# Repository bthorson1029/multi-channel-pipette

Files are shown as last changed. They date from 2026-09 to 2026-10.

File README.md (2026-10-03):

# multi-channel-pipette: motorized-lift redesign

A 96-channel pipette for 8 x 12 well plates, built from low-cost parts: 2020 aluminum extrusion,
laser-cut 3 mm steel, 3D-printed parts, NEMA17 steppers and an Arduino. This fork redesigns
[Its-Triggy/multi-channel-pipette](https://github.com/Its-Triggy/multi-channel-pipette) (build
video: [youtu.be/2TTu-Lkz2Eo](https://youtu.be/2TTu-Lkz2Eo)) to run itself instead of being worked
by hand with a lever. This repo holds only the redesign; the original design's files are in its
history (commit `4b765e6` and earlier).

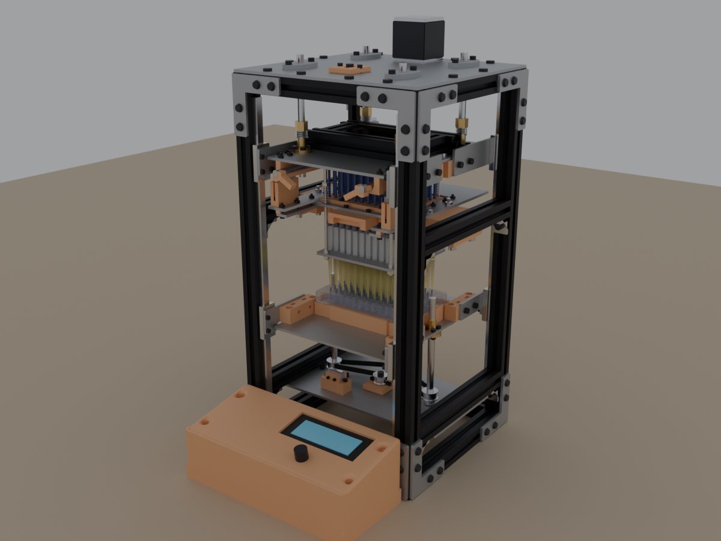
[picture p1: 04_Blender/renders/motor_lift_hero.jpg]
The motorized-lift build mid-dispense


## Status

**Designed and simulated, not yet built.** The whole machine is modeled in Blender down to every
screw. It passes collision and clearance checks through a complete run, and the firmware compiles
for the Uno and passes a host-side test suite. Nothing has been built or run on hardware yet.
Before trusting it with samples, you'll need to measure or set:

- Volume calibration tables for each syringe cartridge (`CAL_*` in `Config.h`)
- Labware heights for your tip rack and reservoir (placeholders in `Config.h`)
- The plunger level-check tolerance (`PLUNGER_TILT_MAX_MM`)
- The KFL08 bolt spacing (the plates assume 37 mm) and your syringes' flange dimensions
- The force needed to strip the tips, and the D-shaft clamp's preload
- The tip cone size for your tips: order the sizing set first (see "Tip cones" in
  [`01_Hardware/README.md`](01_Hardware/README.md))

The frame layout was reconstructed from the original's build video, since the original has no
assembly file. Part shapes are exact; some positions and lengths are estimates.

## What changed from the original

| | Original | This redesign |
|---|---|---|
| Moving the tips into the labware | Lever lowers the whole head | Head fixed; a motor raises the bed on two T8x2 lead screws |
| Plunger drive | 4 motors, one per screw | 1 motor on the top plate drives all 4 T8x2 screws through a GT2 belt |
| Plunger nuts | Plain | Anti-backlash, 2 mm lead (48 steps/uL) |
| Plunger homing | Limit switches | 3 slotted optical sensors, with a check that the plate is level |
| Tip removal | No ejector | Tip ejector: the plunger runs 11.5 mm past home and strips the tips a row at a time |
| Syringes | Fixed in the head | A cartridge that slides out the front like a drawer, held by two quarter-turn levers |
| Control box | Hung on the frame | Lies in front of the base with its screen tilted 10 deg toward you |
| Frame height | 400 mm | 430 mm, so an empty tip rack slides out under freshly loaded tips |

## How a run works

1. **Load tips.** Put a full tip rack in the nest and raise the bed; the nozzles press into the
   tips. Lower the bed and the tips stay on. The empty rack slides out under them.
2. **Aspirate.** Swap in the source (a reservoir or plate), raise the bed so the tips are in the
   liquid, and draw.
3. **Dispense.** Swap in the destination plate, raise the bed, and dispense. Forward mode blows
   out after a single transfer; reverse mode is for repeat dispenses.
4. **Eject.** Put a waste tray on the bed and choose *Eject tips*: the plunger runs past home and
   the ejector plate strips the tips, front rows first.
5. **Swap cartridges.** Loosen the four clamp thumbscrews, turn the two levers a quarter turn and
   slide the cartridge out the front.
   Pick the new one's profile in the *Cartridge* menu.

The Blender model plays this whole run on its timeline (680 frames).

| Tips in the reservoir | Cartridge out |
|---|---|
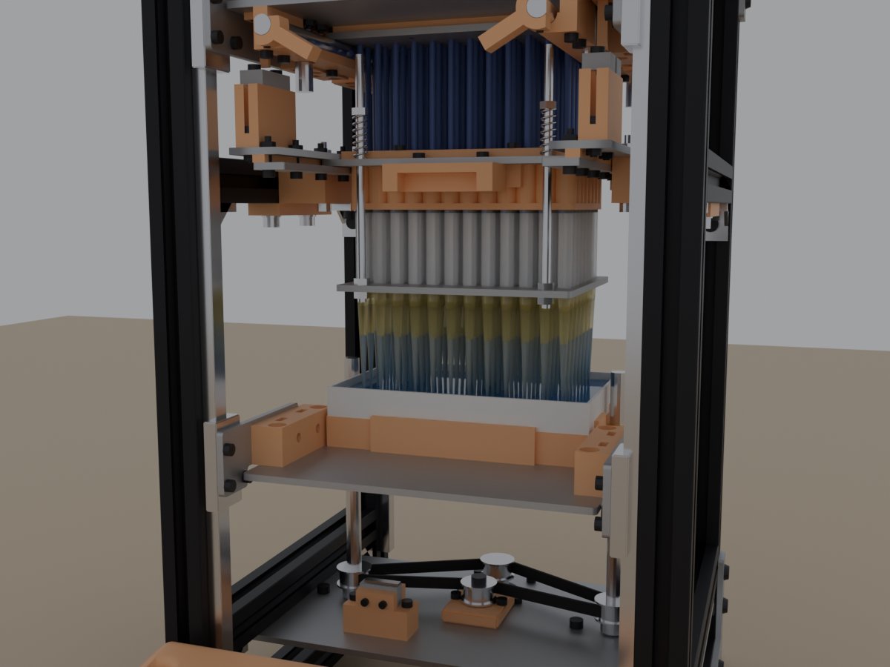
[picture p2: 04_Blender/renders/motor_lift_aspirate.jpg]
Aspirating from a reservoir
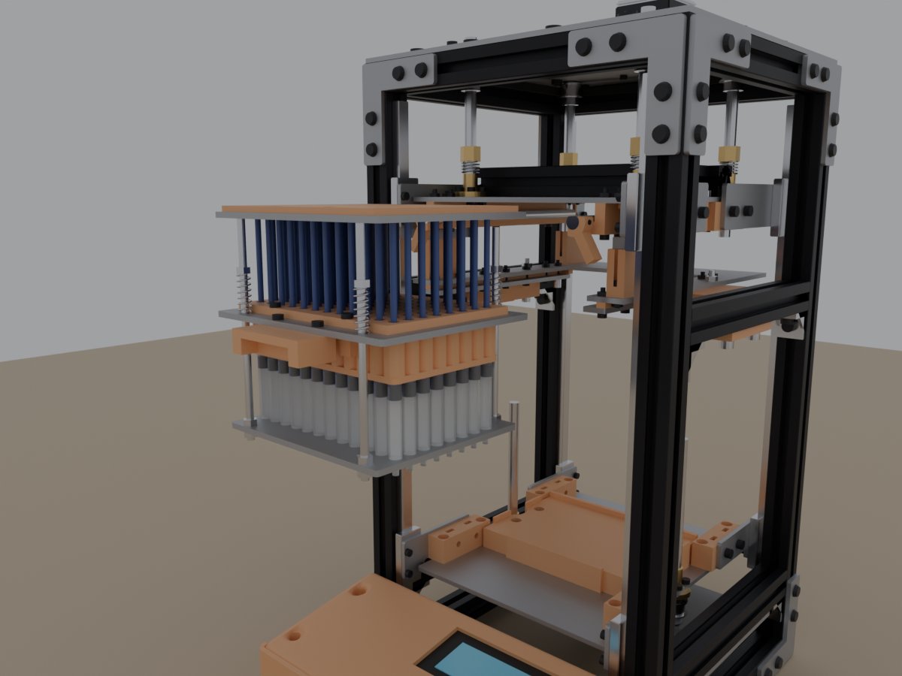
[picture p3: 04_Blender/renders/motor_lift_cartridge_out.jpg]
The syringe cartridge pulled out
|  |  |

## Specs

- **Frame:** 229 x 218 x 430 mm of 2020 T-slot extrusion, with the control box in front
- **Channels:** 96 x 1 mL syringes on a 9 mm pitch, 200 uL tips (a 10 uL profile is stubbed in)
- **Lift:** 40 mm NEMA17, two T8x2 screws on a GT2 belt, 65.9 mm of travel, homed on a limit switch
- **Plunger:** 48 mm NEMA17 on the top plate, four T8x2 screws on a GT2 belt, anti-backlash nuts
- **Electronics:** Arduino Uno, CNC Shield V3, two A4988 or DRV8825 drivers at 1/8 step, 20 x 4
  I2C LCD, rotary encoder, 12 V supply
- **Parts:** 35 laser-cut steel parts (13 DXF files), 32 printed parts plus 96 resin tip cones (21 STL files), about 360
  fasteners. Full list with an order summary: [BOM.md](BOM.md)

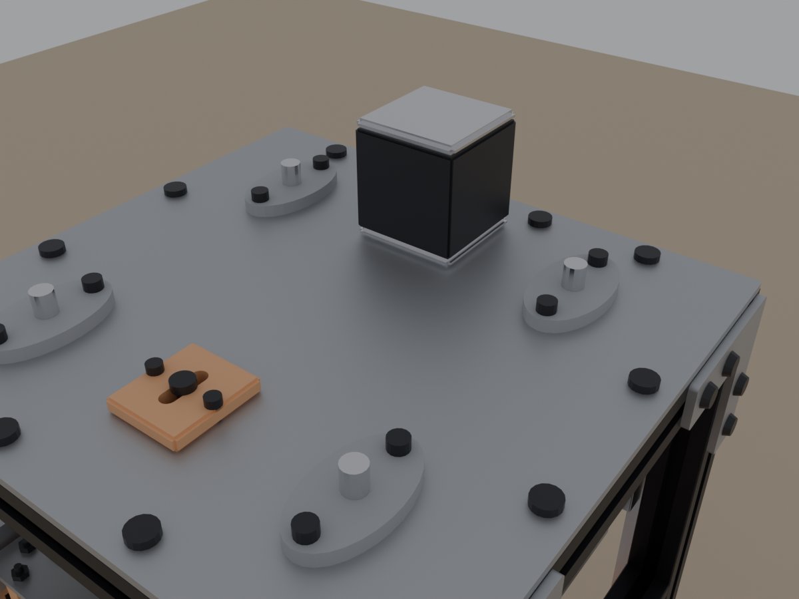
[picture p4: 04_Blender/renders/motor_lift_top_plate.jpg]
The top plate: plunger motor, bearings and belt tensioner


## Repository layout

| Path | What's there |
|---|---|
| [`BOM.md`](BOM.md) | Bill of materials, with totals to order and where to get parts made |
| [`01_Hardware`](01_Hardware) | Every file to fabricate: `ToLaserCut-DXF/` (13 files, 35 parts) and `ToPrint-STL/` (21 files: 32 parts, plus the resin tip cones and their sizing set), plus `make_dxf.py`, which holds the layout numbers. Its README explains each part. |
| [`02_Software`](02_Software) | Firmware (`arduino/MotorLift`; settings in `Config.h`). Its README has the wiring and what each feature does. |
| [`04_Blender`](04_Blender) | Scripts that build the model, check it for collisions and clearances, animate a full run, and write the STLs |

## Regenerating the files

The scripts are the source of truth. Change positions in `make_dxf.py` or `04_Blender/build_pipette.py`,
then regenerate:

```bash
python 01_Hardware/make_dxf.py
```

```bash
blender -b --python 04_Blender/export_parts.py
```

```bash
blender --python 04_Blender/build_pipette.py
```

The first writes the DXFs, the second builds the model and writes the STLs, and the third opens the
model in Blender. The Blender scripts were tested with Blender 5.2; see
[`04_Blender/README.md`](04_Blender/README.md) for what each one builds and checks.

## Credits and license

The original design, firmware and build video are by
[Its-Triggy](https://github.com/Its-Triggy/multi-channel-pipette). This fork keeps its licenses:
hardware under the [CERN Open Hardware Licence v2, Permissive](LICENSE-CERN-OHL), software under
the [MIT License](LICENSE-MIT).

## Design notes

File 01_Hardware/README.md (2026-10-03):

# Fabrication files

Every part to cut or print for the pipette: 13 DXF files for 35 laser-cut parts and 21 STL files
for 32 printed parts plus 96 resin tip cones. Everything else is bought; see [`BOM.md`](../BOM.md) for the full list with
quantities to order. Units are millimeters.

## Laser-cut (`ToLaserCut-DXF/`, 3 mm steel; 304 stainless or coated steel suggested)

Upload the files separately and set each quantity. The generated files don't declare units: choose
millimeters if asked, and check a size (the top plate is 229.2 x 218 mm). Use 3 mm (or 11 gauge)
stock (11 gauge, .119"); the model assumes 3.0 mm. 1/8" (3.18 mm) also fits the cartridge
plate's 3.5 mm channel.

| File | Qty | Notes |
|---|---|---|
| `pipette_plate.dxf` | 1 | 160 x 200 mm: a U open at the front for the cartridge drawer (slot 114 mm wide, to 50 mm behind center), with the head-bracket holes, 6 for the sensor posts and 14 for the drawer channels. |
| `plunger_plate.dxf` | 1 | The drive plate, redrawn at 160 x 200 mm so the carriage brackets sit outside the drawer's clamp troughs: 4 T8 nut cutouts (the nuts sit on it, body up), 8 M4 for the carriage brackets, 6 M3 for the sensor flags, 8 M3 for the troughs. No plunger-rod holes: the rods are the cartridge's. |
| `plunger_rail_plate.dxf` | 4 | Joins the drive plate's carriage brackets to the carriages: the lift rail plate made rectangular and 24 mm longer so it reaches down beside the drive plate; same carriage holes, M4 pair moved into the carriage bracket. |
| `lift_rail_plate.dxf` | 4 | Joins the lift platform's carriage brackets to the carriages: 3 carriage screws, 2 M4 into the bracket. The original design's `interface_plate_high`, redrawn 2 mm wider at the carriage end and at its notch, which left only 0.8 mm of steel beside three holes. |
| `corner_bracket.dxf` | 16 | Frame corners, 4 M5 each into the extrusion (the original design's). Or buy 2020 flat L corner plates. |
| `lift_plate.dxf` | 1 | 156 x 200 lift platform (its edges clear the rail plates' carriage-screw heads) with 2 T8 nut cutouts (body through), 8 holes for the carriage brackets and 4 for the well-plate nest. |
| `top_plate.dxf` | 1 | Across the frame's top ring (12 M5 into it). 4 KFL08s for the plunger screws, the plunger motor (standing on it, shaft down) and the belt-tensioner slot; the pulleys, belt and idler run under it inside the ring. |
| `cart_ledge.dxf` | 2 | The drawer channels' ledges under the pipette plate's arms (drawn for the right; flip one over for the left): 7 M3, a tapped M6 hole for the spring plunger. |
| `cartridge_plate.dxf` | 1 per cartridge | The cartridge's drawer plate, 124 x 100 mm: 96 barrel holes (6.7 mm, for 6.4 mm barrels), 4 ejector-rod holes, 4 frame screws, 2 handle screws, and 2 detent holes for the spring plungers. |
| `plunger_carrier.dxf` | 1 per cartridge | Under the thumb pads, 120 x 100 mm with 96 rod holes and 4 holes to tap M3 for the pad retainer; it rides on the D-shaft clamps and pushes the ejector rods. |
| `syringe_lock_plate.dxf` | 1 per cartridge | Steel plate over the printed locking frame, 111 x 87 mm: 96 holes (5.2 mm) for the plunger rods and 4 M3 for the frame screws, each on a tab for edge distance. Tip loading and the stoppers' drag push the barrels up into it; the printed frame alone would bend about 2 mm per 100 N, this about 0.03 mm. |
| `tip_ejector_plate.dxf` | 1 per cartridge | Tip ejector under the barrel ends, 112 x 102 mm with a 5.8 mm hole around each nozzle, 6 mm holes for its 4 M4 rods (loose, so it can tilt). |
| `lift_base_plate.dxf` | 1 | 229.2 x 120 plate hung under the bed-level side extrusions; lift screws + KFL08s, lift motor, tensioner slot, home-switch holder and 4 M5 mounting holes. |

Each T8 nut mounts through one cloverleaf cutout (the center bore with four 3.4 mm slots out to
the flange screws) instead of a bore and four separate holes, which would leave only 1.2 mm
(lift) and 1.9 mm (plunger) of steel between them. The flange covers the slots and carries the
load; the M3 nuts (5.5 mm across flats) span the 3.4 mm slots on their own.

Checked: all outlines closed; smallest hole 2.5 mm (the plunger carrier's tap holes), most of the
plate thickness. Every hole has at least 1.5 mm of steel to the plate's outer edge (the cartridge
plate's detent holes; everything else 2.2 mm or more), above SendCutSend's 0.91 mm minimum for
instant quoting. The thinnest web is 4.1 mm (drive plate), apart from the cartridge plate's 96
barrel holes, which leave 2.3 mm webs.

After cutting, tap the 4 small (2.5 mm) holes in `plunger_carrier.dxf` for M3, and in each
`cart_ledge.dxf` the detent hole for M6 and the two 3.3 mm clamp holes for M4. For a spare cartridge, order another cartridge plate, lock plate,
plunger carrier and tip ejector plate.

## 3D-printed (`ToPrint-STL/`, PETG suggested, the tip cones in resin; oriented for printing)

| File | Qty | Notes |
|---|---|---|
| `head_bracket.stl` | 2 | Joins the pipette plate to the side bar: 2 M4 up through the plate, 2 M5 up into the bar's bottom slot. Starts at x 69.5, outside the drawer channel. Prints on its side; the same part works on both sides (turn it around). |
| `tensioner_bracket_lift.stl` | 1 | 6.5 mm tall. Idler shoulder bolt in the 12 mm slot, 2 M3 x 12 to the plate, 25 mm apart so their heads clear the idler. |
| `tensioner_bracket_plunger.stl` | 1 | 5.5 mm tall; on the top plate, the idler's bolt goes down through the slot. |
| `control_box_housing_sloped.stl` | 1 | The original design's `ScreenHousing` (in `04_Blender/source/`) with its screen panel tilted 10 deg toward the user (front 17.5 mm lower), a 3 mm skirt that runs every wall down to the base, the lid bosses extended down to it, and a back pad with 2 M5 holes into the bottom front bar. Its USB opening in the front wall (which faces the user once the box lies down) is filled; a panel-mount USB-B socket goes in the left end instead, beside the DC jack, with a short USB-B extension to the Arduino. The panel moves as one piece with the LCD, encoder and Arduino standoffs under it. Prints panel-down. |
| `plunger_carriage_bracket_RF_LB.stl`, `plunger_carriage_bracket_RB_LF.stl` | 2 + 2 | Join the drive plate to its rail plates, hanging under the plate's side edges outside the D-shaft troughs (x 67.5 on). One M4 x 20 down through the plate into a captive nut in a pocket, one M4 x 20 up from a pocket (pocket floors 11.5 mm under the plate, so it goes 5.5 mm into the T-nut) into a T-nut in the stiffener's long bar, and 2 M4 x 12 in from outside through the rail plate into captive nuts in slots from below. Mirror-image hands: RF and LB are one, RB and LF the other. Print plate-face down. |
| `lift_carriage_bracket.stl` | 4 | Joins the lift platform to a rail plate (one per corner, all alike). Sits on the platform with its outer face on the rail plate: 2 M4 x 12 in from outside through the rail plate's holes into captive nuts (slots open at the top), 2 M4 x 16 down through counterbores and the platform. Prints as oriented; its inner face stays 2 mm outside the well plate's path. |
| `optical_switch_post.stl` | 3 | Plunger home-sensor post on the pipette plate's arms: holds a slotted optical endstop laid flat (long side along y), 18.4 mm below the drive plate at home so the plate and flag tab clear it (and its screw heads) with 1.5 mm to spare at the full 11.5 mm eject; a pocket under the slot takes the flag. 2 M3 x 12 through counterbores into the plate. |
| `plunger_flag.stl` | 3 | Hangs from the drive plate (2 M3 x 10 countersunk up from under the tab, flush, nuts on the plate) with a 4 x 2 mm vane that reaches the sensor's beam at home and passes on through the slot. Prints tab down. |
| `well_plate_nest.stl` | 1 | Locates the well plate on the lift platform (replaces the original's flat tray): a 15 mm base (the height the firmware expects), walls 4 mm above it on the back and sides, a 2 mm lip at the front, 0.4 mm clearance around the SBS footprint. 4 M4 x 16 through counterbores into the platform. Cut back 11.5 mm around each lift nut for its flange screws' heads. |
| `control_box_base.stl` | 1 | Closes the control box (replaces the original's lid, which sat between the posts). 4 countersunk M3 self-tappers into the housing bosses. |
| `syringe_lock_frame.stl` | 1 per cartridge | Holds the 96 syringes by their flanges, with the finger tabs trimmed to stubs instead of the flanged end cut off: each flange sits on the cartridge plate in a slot along its row (7.4 mm wide, 1.0 mm deep, so the frame presses 0.2 mm on every flange, enough to cover print and flange tolerance, and the stubs can't turn), and 5.2 mm holes pass the plunger rods. 2 mm thick: it only keys and presses the flanges, while the steel lock plate on top takes the load. 4 M3 x 16 self-tappers go down through the lock plate, the frame and the cartridge plate into the grip's ears. Prints slot side up; use fine layers (0.1-0.15 mm) so the slot depth comes out right. |
| `syringe_grip_slipfit.stl` | 1 per cartridge | The original design's grip (in `04_Blender/source/`) with its 96 holes opened from 6.5 to 6.9 mm, so the barrels slide in; it keeps their lower ends in line. 4 ears take the frame screws, so it hangs from the cartridge plate instead of sliding down the barrels. |
| `pad_retainer.stl` | 1 per cartridge | Over the thumb pads, on the plunger carrier (3 mm): pockets keep the 96 pads captive when the cartridge is out, and it carries the drive plate's push down to them. 4 M3 x 6 countersunk screws hold it to the carrier: the heads sit flush with its top (which bears on the drive plate) and the tips come out flush under the carrier (which rides on the D-shafts). Prints pockets up. |
| `cartridge_handle.stl` | 1 per cartridge | Under the front of the cartridge plate (2 M3 self-tappers): pull the drawer out by it. |
| `cart_spacer_R.stl` | 2 | Drawer channel spacer under the pipette plate's arm, between it and the ledge; its tab at the back is the drawer's stop. Drawn for the right; mirror it for the left. |
| `dshaft_trough_R.stl` | 2 | Under the drive plate, cradling an 8 mm D-shaft along its length (so the shaft can't bend); 4 M3 x 25 up into the plate (2 into T-nuts in the stiffener's long bar); pockets under the plate take the nuts of the front plunger T8 flange screws. Mirror for the left. |
| `dshaft_lever.stl` | 2 | On the front end of each D-shaft, held by an M3 cone-point set screw in a dimple opposite the flat. Pointing inward and down, the flat faces outward and the carrier is clamped; a quarter turn outward (the arm ends up hanging 30 deg out from straight down, about 16 mm clear of the rail plate) brings the flat up and the carrier sinks 0.8 mm onto it. With the lever open, the carrier and the plunger rods slide out past it, so the hub only wraps the shaft about 190 deg: it's trimmed 0.5 mm below the flat, so it stays clear of the carrier even if the flat is filed a little deep and 1.5 mm outside the outer rods, and the arm is 5.6 mm thick. |
| `lift_home_switch_holder.stl` | 1 | For a KW12-type lever micro switch (20 x 10 x 6.4 mm, mounting holes 9.5 mm apart), clamped by 2 M2 through the walls; 2 M3 to the base plate. Check the hole positions against your switch. |

| `tip_cone.stl` | 96 per cartridge, plus spares | Resin (SLA), not FDM. Pushed onto each syringe's Luer-slip nozzle; the tips seal on it. See "Tip cones" below. Prints Luer mouth up. |
| `tip_cone_sizing_set.stl` | 1 | Resin (SLA). Five tip cones in 0.1 mm steps on a bar, smallest at the notched end: order it first to choose the size. |

All 21 are closed solids (every edge shared by exactly two triangles).

## Check against your hardware before cutting

- **KFL08 bolt spacing** is set to 37 mm (`KFL08_BOLTS` in `make_dxf.py`). Measure your bearings.
- **Frame height** and rail lengths: 430 mm posts and 360 mm rails, 30 mm taller than the original design's (whose 400 mm was estimated from its build video), so an empty tip rack slides out under freshly loaded tips. The lift travels 66 mm.
- **Syringes**: the frame and grip assume a 6.4 mm barrel, a 1.2 mm flange, and tabs trimmed so
  the flange is 8.2 x 7.2 mm (typical 1 mL values, `SYR_*` in `04_Blender/build_pipette.py`).
  Measure one of yours; if the flange is thicker, the slot depth follows `SYR_FLANGE_T`.

## Tip ejector

A 3 mm plate under the barrel ends, with a hole around each nozzle that the tip rims can't pass.
Four springs on its M4 rods, between the cartridge plate and a nut, hold it up against the barrel
ends, where it is also the stop the tips seat against when they are loaded. To eject, the plunger
goes on past home: the plunger carrier meets the front rods 1.0 mm below home and the back
rods 5.5 mm below, so the plate tilts (about
5 deg) and strips the tips a few rows at a time, front to back, instead of breaking all 96 loose at
once; at 11.5 mm every tip has been pushed 6 mm off its nozzle. Because the plate goes past home,
the plunger's home sensors are slotted optical endstops with flags, not lever switches. The whole
ejector is part of the syringe cartridge.

Before relying on it, pull one tip off a tip cone with a luggage scale: the plunger drive
has roughly 300-500 N, and the staggering keeps the peak to about two rows of tips.

## Tip cones

A resin sleeve on each syringe's Luer-slip nozzle that the tips seal on (`tip_cone.stl`). Inside
it is the standard female Luer taper (6 %), open right through, so it pushes onto the nozzle like
any Luer-slip fitting; the nozzle's end sits 4.5 mm in. Outside, the seal cone narrows from 5.14
to 4.90 mm over its first 4.6 mm, then a lead-in chamfers it to 4.6 mm. It sits 0.5 mm under the
ejector plate, whose 5.8 mm holes it passes. Because every cone is the same part, every channel
gets the same seal and the same pull-off force.

It is only 5.3 mm long so the ejector pushes every tip fully clear of it: at full eject the
back row (the least-pushed, since the plate tilts) ends 1.0 mm below the cone's end and the front
row 4.2 mm (`eject_clearance()` in the model). A longer cone would leave the tips loose but still
on it, relying on gravity to drop them. The seal therefore sits over the nozzle, in the tip's top
5 mm.

- **Print in resin (SLA), not FDM,** from a service: JLC3DP and Craftcloud both offer it. Choose a
  tough or engineering resin over standard if offered: the wall over the nozzle is only about
  0.45 mm, since the tip's mouth (about 5.3 mm) limits the outside and the nozzle (about 4.2 mm)
  the inside. Order a few spares.
- **Size them first.** The seal-cone diameters are estimates, and tip brands differ.
  `tip_cone_sizing_set.stl` has five cones on a bar, from 0.2 mm under to 0.2 mm over the model's
  size (`CONE_SIZES`), smallest at the notched end. Order it with a box of the tips you'll use,
  cut the cones off the bar, push each onto a syringe and press a tip on by hand. Pick the
  smallest that seals (draw some water and hold it for a minute: no drop forms) and still pulls
  off with a firm tug. Add its offset to `CONE_SEAL` in `04_Blender/build_pipette.py`, rerun
  `export_parts.py`, and order 96 plus spares.
- **Fitting:** push each onto its nozzle with a quarter twist, as you would a Luer-slip fitting.
  A seated Luer taper usually holds harder than a tip does, so the cones should stay put when the
  tips are ejected. If one comes off with its tip, glue it with cyanoacrylate and a polyolefin
  primer (syringe nozzles are polypropylene).

## Syringe cartridge (drawer)

Everything that depends on the syringes and tips is one unit that slides in and out at the front,
like a drawer, so a machine can carry cartridges for different tip families (and a spare to swap in
while one is cleaned or repaired). Each cartridge has its own 96 syringes.

- **Stays on the machine:** frame, lift, pipette plate (a U, open at the front), the plunger drive
  (now on the top plate: motor, belt, screws; the drive plate with its nuts, stiffening frame and
  carriage brackets), home sensors and flags, and the drawer's channels and clamps.
- **In the cartridge:** the cartridge plate with the barrels, locking frame and lock plate, grip and handle; the
  plunger carrier (`plunger_carrier.dxf` + `pad_retainer.stl`) holding the thumb pads captive; the
  tip ejector (plate, rods, springs); the 96 tip cones, sized for its tip family. Out of the
  machine it holds together by itself: the syringe stoppers' friction keeps the plunger carrier
  where it was.
- **Lower level, the cartridge plate:** its edges run in two channels under the pipette plate's
  arms (a steel ledge on a printed spacer, 3.5 mm gap, loose enough never to bind). It slides in
  until it stops against the spacers' tabs at the back, and a spring plunger in each ledge clicks
  into its detent holes. Then four M4 thumbscrews, two up through each ledge, press it up against
  the arms. Without them the plate could shift up and down in the channel as the plunger drags
  the barrels, and that travel would be lost volume (about 17 uL per mm of plunger travel).
- **Upper level, the plunger carrier:** its edges run over two 8 mm D-shafts, each cradled full
  length in a printed trough under the drive plate. With the flats up it slides in freely; a
  quarter turn of each shaft's front lever puts the round side up and presses the carrier against
  the drive plate, so the coupling has no play in either direction (any play would be lost volume).
- **Firmware:** pick the cartridge on the device ("Cartridge"); its entry in `CARTRIDGES`
  (`Config.h`) sets the tip capacity, calibration and tip height.

To swap: empty the tips (eject them, or leave them on: with the bed down they clear the nest) and
take the labware off; Home all (bed down, plunger at its working zero). Loosen the four clamp
thumbscrews a turn, turn the two levers to open, pull the drawer out by its handle. Slide the
other one in until it clicks, turn the levers to clamp, tighten the thumbscrews finger-tight, select it on the device, Home all. The whole path is clear (checked in the model: the
cartridge slides 300 mm straight out the front without touching anything). A new cartridge's
plunger carrier has to sit at the same height as the one that came out; set it once with the
drive plate at its working zero, the syringes' friction keeps it.

## Regenerating

The layout numbers (screw, motor, switch and bracket positions) live in `make_dxf.py`, and the
Blender model reads them from there, so the files and the model stay in sync:

```
python 01_Hardware/make_dxf.py                           # DXFs
blender -b --python 04_Blender/export_parts.py           # STLs (builds the model first)
```

`corner_bracket.dxf` is the original design's drawing, cut as it is; `make_dxf.py` writes every
other DXF, including `lift_rail_plate.dxf` (redrawn from the original's).

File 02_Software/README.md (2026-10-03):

# Firmware

`arduino/MotorLift` runs the pipette on an Arduino Uno with a CNC Shield V3: the plunger motor
in the shield's X slot, the lift motor in the Y slot (Z and A unused). Open `MotorLift.ino` in the
Arduino IDE; every setting is in `Config.h`. It needs the LiquidCrystal I2C library for the LCD.

## Wiring

| Part | Shield connection | Uno pin | `Config.h` |
|---|---|---|---|
| Plunger motor | X driver | D2 step, D5 dir | `PLUNGER_STEP_PIN`, `PLUNGER_DIR_PIN` |
| Lift motor | Y driver | D3 step, D6 dir | `LIFT_STEP_PIN`, `LIFT_DIR_PIN` |
| Driver enable | (shared) | D8 | `EN_PIN` |
| Plunger home sensors (3 slotted optical endstops) | X-, Z-, CoolEn | D9, D11, A3 | `PLUNGER_SW_PINS` |
| Lift home switch (micro switch) | Y- | D10 | `LIFT_SW_PIN` |
| Rotary encoder A / B | serial header | D0 / D1 | `ENCODER_A_PIN`, `ENCODER_B_PIN` |
| Rotary encoder push switch | Hold | A1 | `ENCODER_SW_PIN` |
| 20 x 4 LCD, I2C backpack at 0x27 | SDA / SCL | A4 / A5 | `LCD_ADDR` |

All three plunger sensors are needed (see the level check below). Set `PLUNGER_SW_ACTIVE` to the
level your boards give when the beam is blocked: `HIGH` for most 3D-printer endstop boards, which
then also fail safe when unplugged. Set each driver's microstep jumpers to match
`PLUNGER_MICROSTEPS` / `LIFT_MICROSTEPS` (default 1/8). If an axis runs backwards, flip
`PLUNGER_DISPENSE_LEVEL` or `LIFT_UP_LEVEL`.

The encoder uses D0 and D1, which are also the serial pins, so an upload can fail with it
connected. If it does, turn the encoder 1-3 clicks and try again, unplug it during the upload, or
move it to A0 and A2 in `Config.h`.

## What it does

- **Homing:** on power-up it homes the lift (down), then the plunger. The lift re-zeroes on its
  switch every time it lowers, so lost steps don't accumulate.
- **Plunger level check:** homing sets zero where the first plunger sensor trips, then presses
  on until the other two trip and shows their spread ("Homed, level 0.04"). If one trips more
  than `PLUNGER_TILT_MAX_MM` after the first, the plate is tilted (for example, the belt skipped a
  tooth on one screw) or that sensor is dead: it shows "Level: pin 11 late" and the plunger stays
  un-homed until *Home all* succeeds. `PLUNGER_TILT_MAX_MM` (0.10 mm) is a placeholder: home about
  ten times on the built machine, note the readings, and set it just above the largest.
- **Volumes:** the plunger screws are T8x2 (2 mm lead) with anti-backlash nuts: 48 steps/uL.
  Volumes are capped at the fitted cartridge's tip capacity (200 uL).
- **Two modes:** *Forward* (single transfer: dispense everything, then blow out past the working
  zero) and *Reverse* (repeat dispenses: it draws a little extra and pushes some back first, so
  the nut's slack is already taken up in the dispense direction). *Empty tips* discards what's
  left.
- **Labware heights:** each labware entry (`LABWARE` in `Config.h`) is the bed height where the
  tips are at working depth. The 96-well plate's is set from the model; *Tip loading* and
  *Reservoir* are placeholders to set for your rack and reservoir. Trim them on the device in
  0.1 mm steps; trims are saved to EEPROM. The lift's soft limit is `LIFT_TRAVEL_MM` (66 mm).
- **Cartridge** (menu): pick the syringe cartridge fitted. Each entry in `CARTRIDGES` has its tip
  capacity, its own calibration tables, its reverse-mode extra and preload (scaled to its tips), and a
  tip height offset added to every labware height (keep
  it 0 until measured; the 10 uL entry is a placeholder). Only allowed with the tips empty and the
  bed down; kept in EEPROM.
- **Eject tips** (menu): with the bed down and the tips empty, the plunger goes `EJECT_MM`
  (11.5 mm) past home, pushing the ejector plate down so the tips drop onto whatever is on the bed
  (a waste tray), then comes back up and re-homes.

## Calibration

Each cartridge has its own tables (`CAL_200_FORWARD`, `CAL_200_REVERSE`, and so on in
`Config.h`). Weigh water dispensed at several volumes (1 uL = 1 mg at room temperature; ISO 8655
describes the method) and enter commanded -> measured pairs. A 0.1 mg analytical balance is the
minimum for this; dye and a plate reader are an alternative.

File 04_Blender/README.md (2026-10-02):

# Blender model

Python scripts that build the pipette in Blender (tested with 5.2), check it, and write its
printed parts. The scripts are the source of truth; the `.blend` files they produce are not
committed.

```bash
blender --python 04_Blender/build_pipette.py
```

```bash
blender -b --python 04_Blender/export_parts.py
```

The first builds the model and opens it; the second builds it without the UI and writes the
printed parts to `01_Hardware/ToPrint-STL`. You can also open `build_pipette.py` in Blender's Text
Editor and use **Run Script**. Units are millimeters (Z up, front = -Y).

## Files

| File | What it is |
|---|---|
| `build_pipette.py` | The build: lift, plunger drive, syringe cartridge, control box, fasteners, demo labware, the animated run, and the checks. Layout numbers come from `01_Hardware/make_dxf.py`. |
| `pipette_lib.py` | Helpers (materials, mesh, DXF and STL import, T-slot extrusion) and the base parts: frame, corner brackets, well plate, pipette and drive plates, plunger rail plates, the grip and the control box as the original design had them. Not run on its own. |
| `export_parts.py` | Builds the model and writes each printed part as an STL, oriented for printing. It refuses to write a part with holes in its surface. |
| `source/` | Three STLs from the original design that printed parts are derived from: `ScreenHousing.STL` (the sloped control-box housing), `syringe_grip_static.STL` (the slip-fit grip) and `electronics_lid.STL` (used only to position the box). Not printed as they are. |
| `renders/` | Images used in the READMEs. |

## Where the geometry comes from

- **Imported:** the laser-cut parts from `01_Hardware/ToLaserCut-DXF` (lines, arcs and holes,
  extruded to 3 mm steel), and the three `source/` STLs.
- **Modeled:** 2020 T-slot extrusion (B-type 6 mm slot profile), every screw, bolt, nut and
  T-nut in the BOM (`fasteners()`, one `fast_*` object per joint), MGN9H rails and carriages,
  NEMA17 motors, T8 screws and nuts, syringes, tip cones, tips, labware, bearings, pulleys and
  belts. The printed parts are modeled as closed solids so `export_parts.py` can write them
  straight to STL.
- **Layout:** the frame layout was reconstructed from the original design's build video
  (youtu.be/2TTu-Lkz2Eo), then raised 30 mm (430 mm posts). Part shapes are exact; syringe and
  tip dimensions and some mounting positions are estimates.

## Checks

- `collision_report()` sweeps every moving part through its full travel (lift, plunger, tip
  eject) and tests it against the rest of the model, allowing only intended contacts (screws in
  nuts, carriages on rails, and so on). It reports no collisions.
- `fasteners()` checks every fastener as it places it: T-nut bolts must end 4.2-6.0 mm into the
  slot, nut bolts must pass through their nut, and screws into a part must get enough thread;
  any that don't are printed.
- `eject_clearance()` gives, per row, how far below the tip cones' ends the tips are pushed at
  full eject: 1.0 mm (back row) to 4.2 mm (front), so every tip comes fully off its cone.
- The build reports the belt loop lengths across each tensioner's adjustment range: 338.9-344.4
  mm (lift) and 538.7-544.6 mm (plunger).

## The animated run

The timeline plays a complete run (`CYCLE`, 680 frames); scrub it to watch:

1. It starts with no tips. A tip rack goes into the nest, the bed rises 62 mm to press the nozzles
   into the tips, and the tips stay on the nozzles when the bed goes down. The empty rack then
   slides out under them.
2. A reservoir replaces the rack, and the plunger draws 100 uL per channel with the tips in the
   liquid.
3. A 96-well plate replaces the reservoir, and the plunger dispenses into its wells.
4. A waste tray replaces the plate. The plunger runs 11.5 mm past home, and the tilted ejector
   plate strips the tips a row at a time, front row first; they drop into the tray.
5. The drawer clamps back off, the D-shaft levers open (the flats come up and the plunger carrier
   sinks 0.8 mm onto them), and the syringe cartridge slides 210 mm out the front.

The labware (`tip_rack`, `reservoir`, `well_plate_96`, `waste_tray`) is demo-only and is loaded
from the front over the nest's lip. Anything that goes in or out while tips are on has to pass
under them with the bed down (71 mm): the 61 mm rack clears by 10 mm. The tips are ejected into a
30 mm tray.

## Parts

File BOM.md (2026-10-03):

# Bill of materials

For the pipette: fixed head, lead-screw bed lift, one belt-synced plunger motor (model:
`04_Blender/build_pipette.py`, firmware: `02_Software/arduino/MotorLift`). Quantities are counted
from the Blender model. The frame layout was reconstructed from the original design's build video,
so treat lengths marked *est.* as starting points and confirm against your own frame.

Every file to cut or print is in `01_Hardware` (paths below are relative to it); its
[README](01_Hardware/README.md) describes each part and how to regenerate the files.

## Order summary

Totals for one machine with one syringe cartridge, checked against the Blender model.
Fastener quantities include about 20 % extra; the sections below say where each part
goes.

**To have made**
- Laser-cut, 3 mm steel: 35 parts from 13 DXF files (sections 1 and 5b). The 16 frame corner
  brackets can be bought instead.
- 3D-printed: 32 parts from 19 STL files (sections 2 and 5b). Mirror `cart_spacer_R` and
  `dshaft_trough_R` for the left side.
- Resin-printed (SLA): 96 tip cones plus spares, and one sizing set to order first (section 5b).

**Frame and motion**
- 2020 extrusion, 12 bars to cut: 4 x 430 mm *est.*, 4 x 189.2 mm, 8 x 178 mm, 2 x 150 mm,
  2 x 44 mm (about 4.3 m in total)
- 2020 inside corner brackets: 12
- MGN9 rail, 360 mm *est.*: 4; MGN9H carriages: 8
- NEMA17 steppers: 1 x 40 mm body (lift), 1 x 48 mm body (plunger)
- T8x2 lead screw: 6 pieces (4 x ~131 mm, 2 x ~148 mm); anti-backlash nuts: 4; flange nuts: 2
- KFL08 flange bearings: 6
- GT2 20T pulleys: 6 x 8 mm bore, 2 x 5 mm bore; 16 mm smooth idlers: 2
- GT2 6 mm closed loops: 1 x 339-344 mm, 1 x 539-544 mm
- 8 mm steel rod: 2 x ~165 mm (D-shafts)
- M6 ball spring plungers: 2; M4 x 6 knurled thumbscrews (head 10 mm or less): 4
- KW12-type micro switch: 1; slotted optical endstop boards: 3

**Electronics:** Arduino Uno, CNC Shield V3, 2 stepper drivers, 20x4 I2C LCD, rotary encoder,
panel-mount USB-B extension, 12 V 5 A supply with a DC socket (optional LM2596), wire and
Dupont leads.

**Cartridge supplies:** 96 1 mL Luer-slip syringes plus spares, 4 x ~110 mm
M4 threaded rod, 4 light springs (~6.4 mm OD x 20-25 mm).

**Fasteners** (with ~20 % extra)

| Size | Buy |
|---|---|
| M5 x 8 button head | 96 |
| M5 x 10 | 29 |
| M5 x 12 | 5 |
| M5 x 14 | 3 |
| M5 washer | 5 |
| M5 T-nut (2020) | 132 |
| M4 x 12 | 34 |
| M4 x 16 | 15 |
| M4 x 20 | 10 |
| M4 x 30 | 5 |
| M4 hex nut | 72 |
| M4 washer | 15 |
| M4 T-nut (2020) | 5 |
| M3 x 6 | 29 |
| M3 x 8 | 96 |
| M3 x 10 | 29 |
| M3 x 12 | 15 |
| M3 x 14 | 17 |
| M3 x 20 | 3 |
| M3 x 25 | 10 |
| M3 x 10 countersunk | 8 |
| M3 x 6 countersunk | 5 |
| M3 hex nut | 75 |
| M3 T-nut (2020) | 92 |
| M3 x 6 cone-point set screw | 3 |
| M3 self-tapping: pan x 8 / pan x 10 / pan x 16 / countersunk x 10 | 8 / 3 / 5 / 5 |
| M2 x 20 + nut | 3 |
| Shoulder bolt + nut (idlers) | 2 |

## 1. Laser-cut metal

The model assumes **3 mm steel** (11 gauge, .119"); 1/8" (3.18 mm) also fits. The machine
works around liquids, so consider 304 stainless or a coated steel over bare mild steel. Aluminum
would be lighter but about 3x more flexible, which costs plunger accuracy.

| Part | Qty | File | Notes |
|---|---|---|---|
| Pipette plate | 1 | `ToLaserCut-DXF/pipette_plate.dxf` | A U open at the front for the cartridge drawer; head-bracket, sensor-post and channel holes. |
| Plunger (drive) plate | 1 | `ToLaserCut-DXF/plunger_plate.dxf` | 160 x 200 mm: 4 T8 nut cutouts, 8 carriage-bracket holes, 3 sensor flags, 8 trough bolts; no plunger-rod holes. |
| Top plate | 1 | `ToLaserCut-DXF/top_plate.dxf` | On the top ring: the plunger screws' KFL08s, the plunger motor, the belt tensioner. |
| Drawer channel ledge | 2 | `ToLaserCut-DXF/cart_ledge.dxf` | Flip one over for the left side. Tap the M6 hole and the two clamp holes (M4). |
| Lift platform | 1 | `ToLaserCut-DXF/lift_plate.dxf` | 156 x 200 mm (its edges clear the rail plates' carriage-screw heads), 2 T8 nut cutouts, 8 carriage-bracket holes, 4 well-plate-nest holes. |
| Lift base plate | 1 | `ToLaserCut-DXF/lift_base_plate.dxf` | 229.2 x 120 mm. |
| Lift rail plate | 4 | `ToLaserCut-DXF/lift_rail_plate.dxf` | Joins the lift platform's brackets to the carriages. |
| Plunger rail plate | 4 | `ToLaserCut-DXF/plunger_rail_plate.dxf` | A taller, rectangular lift rail plate that reaches down to the plunger carriage brackets. |
| Frame corner bracket | 16 | `ToLaserCut-DXF/corner_bracket.dxf` | Or buy 2020 flat L corner plates. |

The syringe cartridge's four plates are in section 5b.

## 2. 3D-printed parts

PETG is a good default for the load-bearing parts. Suggested:
4 perimeters, 40 % infill. The largest part (the sloped housing, 218 x 111 x 75 mm) needs a bed of at
least 220 mm.

| Part | Qty | File | Notes |
|---|---|---|---|
| Plunger sensor post | 3 | `ToPrint-STL/optical_switch_post.stl` | Holds a slotted optical endstop laid flat under the plunger plate; 2 M3 to the pipette plate. |
| Plunger sensor flag | 3 | `ToPrint-STL/plunger_flag.stl` | Hangs from the plunger plate through the sensor's slot; 2 M3. |
| Electronics housing (sloped) | 1 | `ToPrint-STL/control_box_housing_sloped.stl` | The original design's housing with the screen panel tilted 10 deg toward the user, a skirt that runs its walls down to the bench, the lid bosses extended to the base, and a back pad with 2 M5 into T-nuts in the bottom front bar. |
| Control box base | 1 | `ToPrint-STL/control_box_base.stl` | Closes the housing's underside (replaces the original's lid, which was sized to sit between the posts). 4 countersunk M3 into the bosses. |
| Well-plate nest | 1 | `ToPrint-STL/well_plate_nest.stl` | Locates an SBS plate on the lift platform at the height the firmware expects (replaces the original's flat tray). 4 M4 to the platform. |
| Head bracket | 2 | `ToPrint-STL/head_bracket.stl` | Bolts the pipette plate to the side bars. |
| Belt tensioner bracket (lift) | 1 | `ToPrint-STL/tensioner_bracket_lift.stl` | |
| Belt tensioner bracket (plunger) | 1 | `ToPrint-STL/tensioner_bracket_plunger.stl` | On the top plate. |
| Drawer channel spacer | 1 + 1 mirrored | `ToPrint-STL/cart_spacer_R.stl` | Mirror for the left. |
| D-shaft trough | 1 + 1 mirrored | `ToPrint-STL/dshaft_trough_R.stl` | Mirror for the left. |
| D-shaft lever | 2 | `ToPrint-STL/dshaft_lever.stl` | |
| Plunger carriage bracket | 2 + 2 | `ToPrint-STL/plunger_carriage_bracket_RF_LB.stl`, `ToPrint-STL/plunger_carriage_bracket_RB_LF.stl` | Hang under the plunger plate's side edges and join it to its 4 rail plates. Two mirror-image hands, 2 of each. 4 captive M4 nuts each. |
| Lift carriage bracket | 4 | `ToPrint-STL/lift_carriage_bracket.stl` | Joins the lift platform to its 4 rail plates; same part at every corner. 2 captive M4 nuts each. |
| Lift home-switch holder | 1 | `ToPrint-STL/lift_home_switch_holder.stl` | For a KW12-type switch. |

## 3. Frame and motion

| Part | Qty | Notes |
|---|---|---|
| 2020 aluminum extrusion, 430 mm *est.* | 4 | Posts. 30 mm taller than the original design, so an empty tip rack slides out under freshly loaded tips. |
| 2020 extrusion, 189.2 mm | 4 | Front/back of the bottom and top rings. |
| 2020 extrusion, 178 mm | 8 | Sides of the bottom, bed-level and top rings, plus the two head side bars. |
| 2020 inside corner bracket | 12 | Head side bars (4) and bed-level side bars (4) to the posts; stiffening-frame corners (4). |
| 2020 extrusion, 150 mm | 2 | Plunger-plate stiffening frame. |
| 2020 extrusion, 44 mm | 2 | Plunger-plate stiffening frame. |
| MGN9 linear rail, 360 mm *est.* | 4 | One per post. |
| MGN9H carriage | 8 | Lift platform (4) + plunger plate (4). |
| NEMA17 stepper, 40 mm body (~0.4 N m) | 1 | Lift. 5 mm shaft. |
| NEMA17 stepper, 48 mm body (~0.5 N m) | 1 | Plunger (drives all four screws). Stands on the top plate, shaft down. |
| T8x2 lead screw (8 mm, 2 mm lead) | 6 | Buy 150 mm: cut 4 plunger screws to ~131 mm (hung from the top plate); use 2 uncut for the lift (~148 mm needed for 66 mm of travel). |
| T8x2 anti-backlash nut | 4 | Plunger. |
| T8x2 brass flange nut | 2 | Lift (gravity keeps these loaded one way). |
| KFL08 flange bearing (8 mm bore) | 6 | 4 plunger (on the top plate), 2 lift. The plates assume 37 mm bolt spacing; check yours. |
| GT2 20T pulley, 8 mm bore, 6 mm belt | 6 | On the screws. |
| GT2 20T pulley, 5 mm bore, 6 mm belt | 2 | On the motors. |
| Smooth idler, 16 mm OD, 6 mm belt | 2 | Tensioners, each on a shoulder bolt. |
| GT2 closed-loop belt, 6 mm, 339-344 mm | 1 | Lift. Any loop in this range fits the tensioner's adjustment. |
| GT2 closed-loop belt, 6 mm, 539-544 mm | 1 | Plunger, under the top plate. Any loop in this range fits the tensioner's adjustment. |
| Steel rod, 8 mm, ~165 mm | 2 | Drawer D-shafts: grind or file a 0.8 mm deep flat along the length, and drill a 2.5 mm dimple 1.5 mm deep, 4 mm from the front end, opposite the flat. |
| M3 x 6 cone-point set screw | 2 | Holds each lever on its D-shaft (into the dimple). |
| Ball spring plunger, M6 | 2 | Drawer detents, in the ledges. |
| Knurled thumbscrew, M4 x 6, head 10 mm across or less | 4 | Drawer clamps: up through the ledges' tapped holes, pressing the cartridge plate against the pipette plate's arms. A bigger head hits the barrels as the drawer slides. |
| Micro limit switch (lever type, KW12-style) | 1 | Lift home. |
| Slotted optical endstop board (TCST2103-type, 3D-printer style) | 3 | Plunger home, one per sensor post. Check the body (24.5 x 10.8 x 6.3 mm, 3.1 mm slot, M3 ears 19 mm apart) and the output level when blocked (`PLUNGER_SW_ACTIVE`). |

## 4. Electronics

| Part | Qty | Notes |
|---|---|---|
| Arduino Uno | 1 | |
| CNC Shield V3 | 1 | Plunger in X, lift in Y. |
| Stepper driver (A4988 or DRV8825) | 2 | Set to 1/8 microstepping (first two jumpers on for either). |
| 20x4 LCD with I2C backpack (address 0x27) | 1 | |
| Rotary encoder with push switch | 1 | |
| Panel-mount USB-B extension, B female (panel) to B male, ~30 cm | 1 | Arduino USB out through the control box's left end, beside the DC jack. Typical socket: 12.5 x 11.5 mm cutout, M3 ears 30 mm apart; check yours against `USB_PANEL_*` in the model. |
| 12 V power supply, 5 A suggested | 1 | Plus a DC socket for the housing. |
| LM2596 buck converter | 1 | Optional (the original design used one). |
| Wire, Dupont leads, heat-shrink | | |

## 5. Pipetting consumables

| Part | Qty | Notes |
|---|---|---|
| Pipette tips, racked | as needed | For the cartridge fitted; the firmware caps volumes at the cartridge's tip capacity. |
| 96-well plates (SBS format) | as needed | |

## 5b. Syringe cartridge (per cartridge)

Everything that depends on the syringes and tips (see "Syringe cartridge" in
`01_Hardware/README.md`). Build one per tip family, or a spare.

| Part | Qty | File / notes |
|---|---|---|
| Cartridge plate, 3 mm steel | 1 | `ToLaserCut-DXF/cartridge_plate.dxf` |
| Plunger carrier, 3 mm steel | 1 | `ToLaserCut-DXF/plunger_carrier.dxf`; tap the 4 small (2.5 mm) holes M3 |
| Tip ejector plate, 3 mm steel | 1 | `ToLaserCut-DXF/tip_ejector_plate.dxf` |
| Syringe locking frame (printed) | 1 | `ToPrint-STL/syringe_lock_frame.stl`; a slot per row keys the tab stubs |
| Syringe lock plate, 3 mm steel | 1 | `ToLaserCut-DXF/syringe_lock_plate.dxf`; over the frame, holds the flanges against tip loading and stopper drag |
| Syringe barrel grip, slip fit (printed) | 1 | `ToPrint-STL/syringe_grip_slipfit.stl`; hangs from the cartridge plate by 4 ears |
| Pad retainer (printed) | 1 | `ToPrint-STL/pad_retainer.stl`; countersunk for 4 M3 |
| 1 mL Luer-slip syringes | 96 + spares | Plungers sanded from 9.5 to 8 mm in a drill so they fit the 9 mm spacing (per the build video). Buy from one batch so the bores match. Instead of cutting the flanged end off, trim the finger tabs to stubs: flange 8.2 mm across the stubs and at most 7.2 mm wide, face left flat (the model assumes a 6.4 mm barrel and a 1.2 mm flange; measure yours). |
| Tip cone (resin-printed) | 96 + spares | `ToPrint-STL/tip_cone.stl`, SLA in a tough resin if offered. Pushed onto each Luer nozzle; the tips seal on it. Size it with the sizing set first (see "Tip cones" in `01_Hardware/README.md`). |
| Tip cone sizing set (resin-printed) | 1 | `ToPrint-STL/tip_cone_sizing_set.stl`: five sizes on a bar, smallest at the notched end. |
| M4 threaded rod, ~110 mm | 4 | Tip-ejector rods |
| Compression spring, ~6.4 mm OD x 20-25 mm, light | 4 | Hold the ejector plate up; one over each rod |
| M4 nut + washer | 12 | Ejector rods: under and over the plate, and the spring stop |
| Cartridge handle (printed) | 1 | `ToPrint-STL/cartridge_handle.stl` |
| M3 x 10 self-tapping | 2 | Handle to the cartridge plate |
| M3 x 16 self-tapping | 4 | Lock plate, frame and cartridge plate into the grip's ears |
| M3 x 6 countersunk (ISO 10642) | 4 | Pad retainer down into the carrier's tapped holes; heads flush on top, tips flush underneath |

## 6. Fasteners

Counted from the Blender model, which places every one of them (the `fast_*` objects; see
`fasteners()` in `04_Blender/build_pipette.py`). Lengths were checked against each stack:
T-nut bolts end 4.2-6.0 mm into the slot (through the T-nut, short of the 2020 core), nut bolts
pass through their nut, and screws into plastic, motors or carriages get enough thread. Buy about
20 % extra. The cartridge's own screws are in section 5b.

| Fastener | Qty | Where |
|---|---|---|
| M5 x 8 button head + M5 T-nut (2020) | 80 | Corner brackets (64), top plate (12), base plate (4): 3 mm plates, so 5 mm into the slot. An M5 x 10 would go 7 mm in and bottom out on the extrusion's core (6.1 mm deep) before it clamps. |
| M5 x 10 + M5 T-nut (2020) | 24 | Inside corner brackets: head and bed-level side bars to the posts (16), stiffener corners (8) |
| M5 x 12 + M5 washer + M5 T-nut (2020) | 4 | Head brackets' feet up into the side bars |
| M5 x 14 + M5 T-nut (2020) | 2 | Control box to the bottom front bar, through the 3 mm back wall and the pad |
| M4 x 12 + nut | 28 | KFL08 bearings through the plate and the 5 mm flange (12); rail plates into the carriage brackets' captive nuts (16) |
| M4 x 16 + nut | 12 | Lift brackets down through the platform (8); well-plate nest (4) |
| M4 x 20 + M4 T-nut (2020) | 4 | Plunger carriage brackets: up from the bracket's pocket into the stiffener's long bar |
| M4 x 20 + nut | 4 | Plunger carriage brackets: down through the drive plate into the bracket's pocket |
| M4 x 30 + nut | 4 | Head brackets up through the pipette plate |
| M3 x 6 | 24 | MGN9H carriages to the rail plates (3 each, into the carriage) |
| M3 x 8 | 8 | Motors, into their faces |
| M3 x 8 + M3 T-nut (2020) | 72 | MGN9 rails into the posts (20 mm pitch) |
| M3 x 10 + nut | 24 | T8 nut flanges. Lift (8): heads on the platform, nuts under the flange (they clear the pulley by 1 mm with the bed down). Plunger (16): heads on the flange, nuts under the drive plate (pockets in the D-shaft troughs take the front ones). |
| M3 x 10 countersunk + nut | 6 | Plunger home flags: flush under the tab (it passes over the sensor at full eject), nuts on the drive plate |
| M3 x 10 countersunk, self-tapping | 4 | Control box base into the housing bosses |
| M3 x 12 + nut | 12 | Sensor posts to the pipette plate (6), tensioner brackets (4), USB panel socket (2) |
| M3 x 14 + nut | 14 | Drawer ledges and spacers to the pipette plate |
| M3 x 20 + nut | 2 | Lift home-switch holder to the base plate |
| M3 x 25 + nut | 4 | D-shaft troughs to the drive plate (front) |
| M3 x 25 + M3 T-nut (2020) | 4 | D-shaft troughs into the stiffener's long bars |
| M3 x 8 pan-head self-tapping | 6 | Optical endstops to their posts |
| M2 x 20 + nut | 2 | Lift home switch through its holder's walls |
| Shoulder bolt + nut | 2 | Tensioner idlers |

## 7. Tools and supplies

- Hacksaw or cut-off wheel (lead screws); calipers
- Drill (sanding the syringe plungers to 8 mm)
- Light lubricant for the lead screws
- For calibration: a 0.1 mg analytical balance, or dye plus a plate reader (see
  `02_Software/README.md`)

## Where to get things made

**Laser-cut metal** (upload DXF; all quote instantly online):
- [SendCutSend](https://sendcutsend.com/) (US): DXF/DWG/AI/STEP; 175+ materials; holes must be at
  least 50 % of the material thickness (fine for 3 mm; the smallest holes here are 3.2 mm, in the
  plunger plate).
- [OSH Cut](https://www.oshcut.com/) (US): DXF and most CAD formats; next-day options.
- [Fabworks](https://www.fabworks.com/) (US): online laser cutting.
- [JLCCNC sheet metal](https://jlccnc.com/sheet-metal-fabrication) (China): its quote flow
  expects a STEP file; low minimums.
- [PCBWay laser cutting](https://www.pcbway.com/rapid-prototyping/Sheet-metal/Laser-Cutting.html),
  [Xometry](https://www.xometry.com/capabilities/sheet-metal-fabrication/),
  [Protolabs](https://www.protolabs.com/services/sheet-metal-fabrication/laser-cutting/)

**3D printing** (upload STL; choose SLA resin for the tip cones):
- [Craftcloud](https://craftcloud3d.com/): compares quotes from 150+ print services.
- [JLC3DP](https://jlc3dp.com/): FDM, SLA, MJF and SLS; low per-part prices.
- [Xometry](https://www.xometry.com/capabilities/3d-printing-service/): also PLA/PETG FDM.
- Or a local makerspace/library printer: every part fits a common 220 mm bed.

**CNC machining**: not needed for this design, since every metal part is a flat laser-cut plate.
Worth considering only for upgrades, e.g. machined aluminum plates or reamed bearing holes:
[Xometry](https://www.xometry.com/capabilities/cnc-machining-service/), [JLCCNC](https://jlccnc.com/),
or PCBWay.

**Extrusion, rails and motion parts**: printer-parts suppliers, MISUMI (cut-to-length extrusion
and rails), or Amazon/AliExpress for the generic parts (NEMA17, T8 screws and nuts, KFL08, GT2).

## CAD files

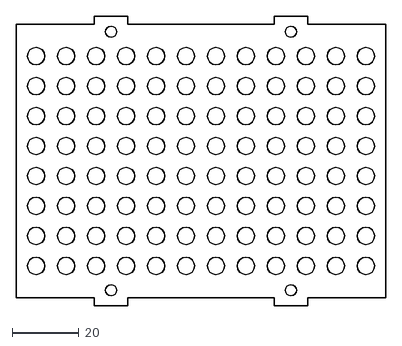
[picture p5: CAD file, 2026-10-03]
01_Hardware/ToLaserCut-DXF/syringe_lock_plate.dxf
111.0 x 87.0

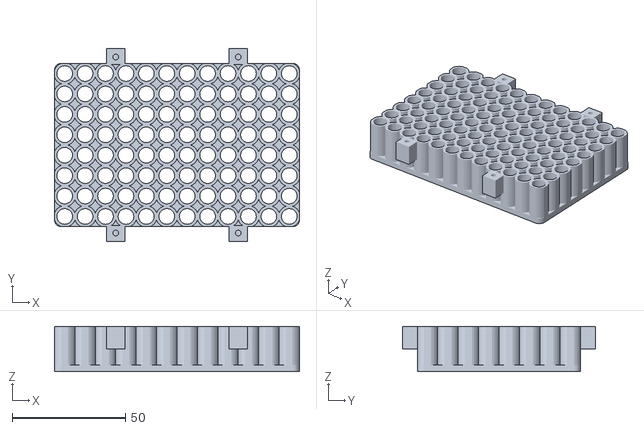
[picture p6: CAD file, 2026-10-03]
01_Hardware/ToPrint-STL/syringe_grip_slipfit.stl
108.0 x 85.0 x 20.0

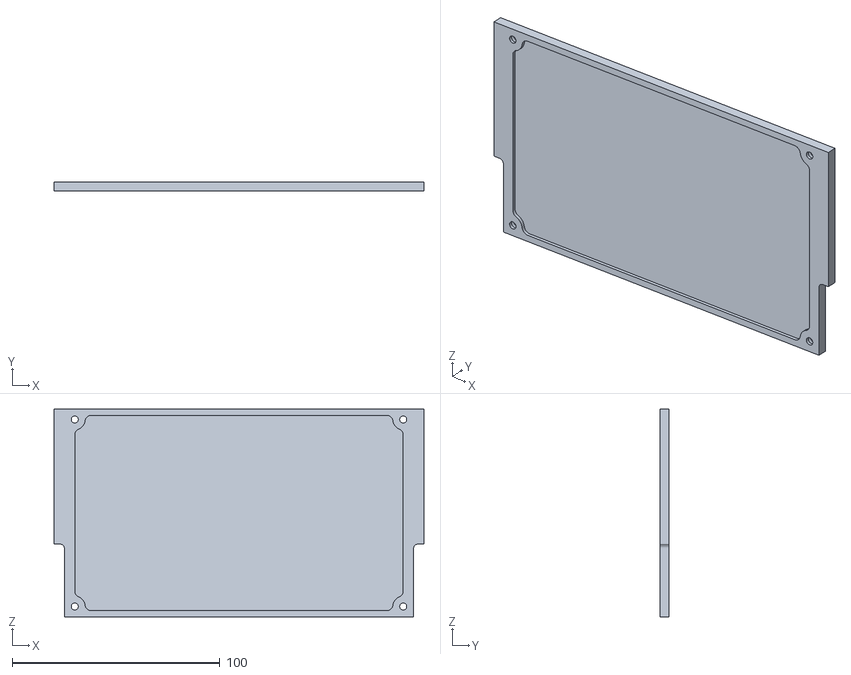
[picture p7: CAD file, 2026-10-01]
04_Blender/source/electronics_lid.STL
178.0 x 4.50 x 100.0

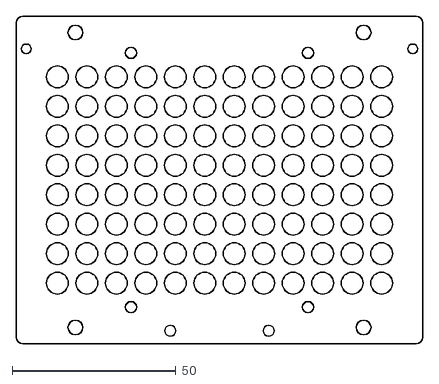
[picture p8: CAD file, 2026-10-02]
01_Hardware/ToLaserCut-DXF/cartridge_plate.dxf
124.0 x 100.0

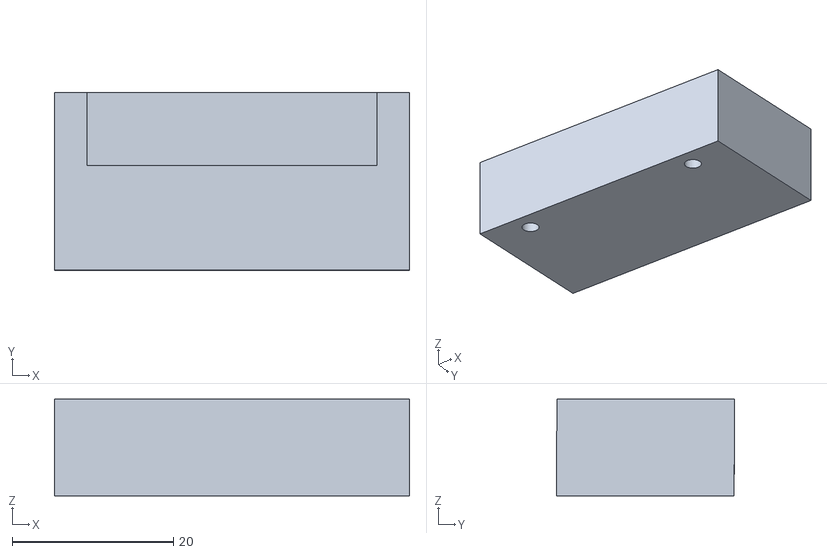
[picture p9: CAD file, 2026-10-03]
01_Hardware/ToPrint-STL/cartridge_handle.stl
44.0 x 22.0 x 12.0

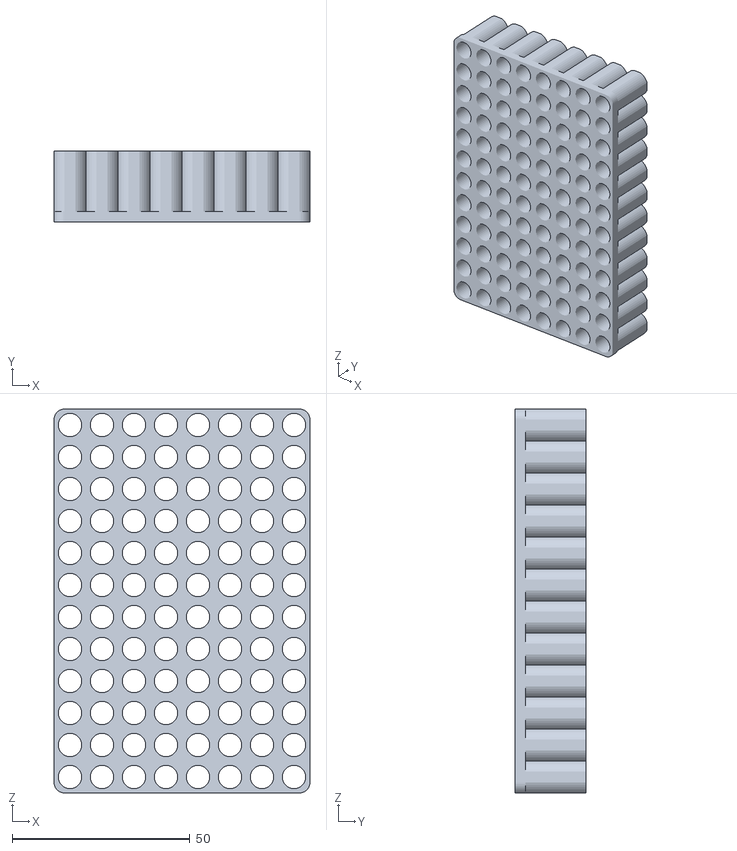
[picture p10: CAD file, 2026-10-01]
04_Blender/source/syringe_grip_static.STL
72.0 x 20.0 x 108.0

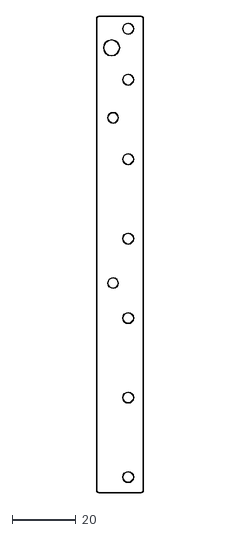
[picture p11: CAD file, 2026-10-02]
01_Hardware/ToLaserCut-DXF/cart_ledge.dxf
14.7 x 150.0

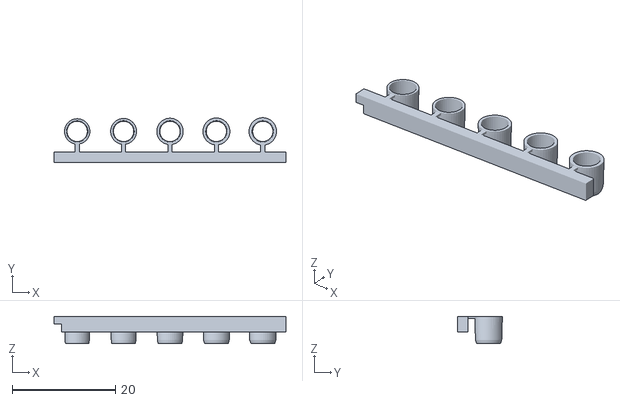
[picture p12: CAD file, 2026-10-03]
01_Hardware/ToPrint-STL/tip_cone_sizing_set.stl
45.0 x 8.67 x 5.30

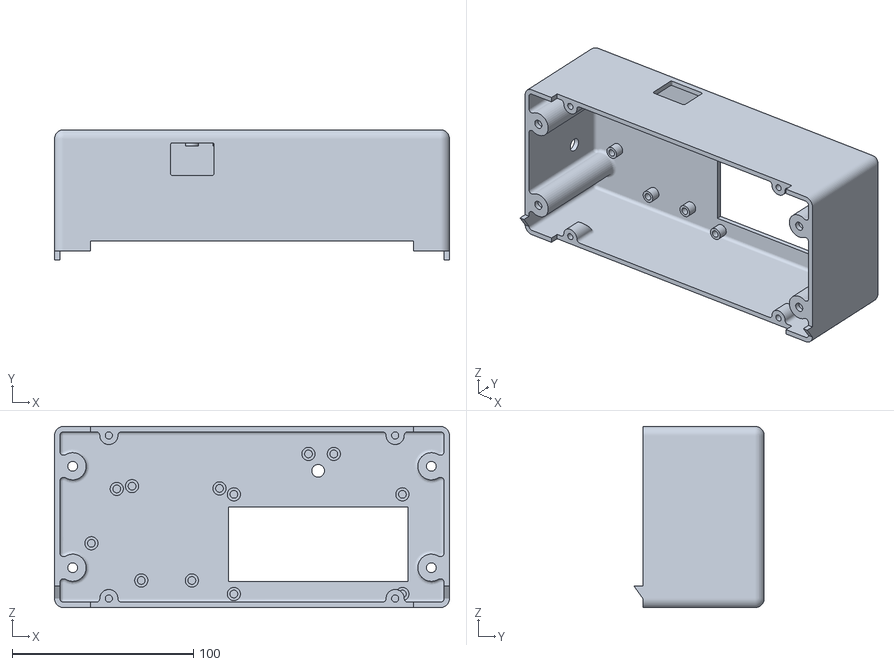
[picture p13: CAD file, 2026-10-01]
04_Blender/source/ScreenHousing.STL
218.0 x 72.0 x 100.0

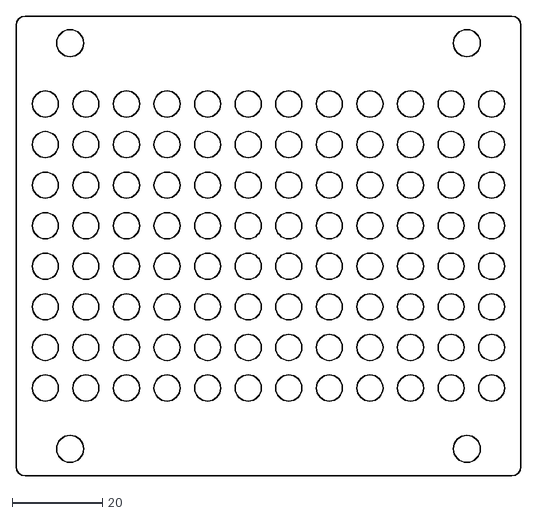
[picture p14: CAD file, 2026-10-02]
01_Hardware/ToLaserCut-DXF/tip_ejector_plate.dxf
112.0 x 102.0

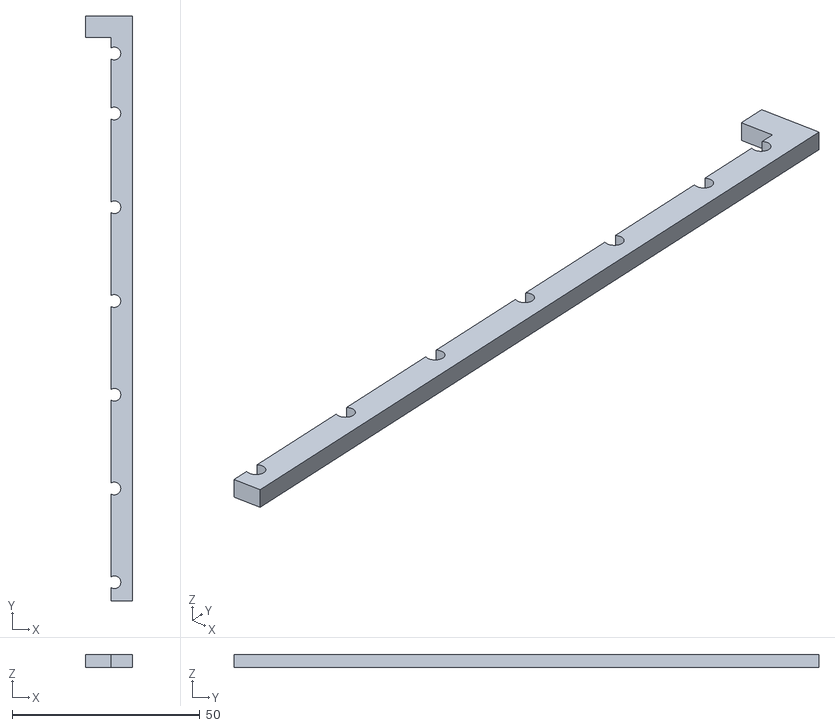
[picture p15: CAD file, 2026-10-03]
01_Hardware/ToPrint-STL/cart_spacer_R.stl
12.5 x 156.0 x 3.50

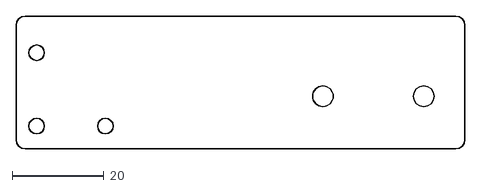
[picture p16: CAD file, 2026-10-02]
01_Hardware/ToLaserCut-DXF/plunger_rail_plate.dxf
98.0 x 29.0

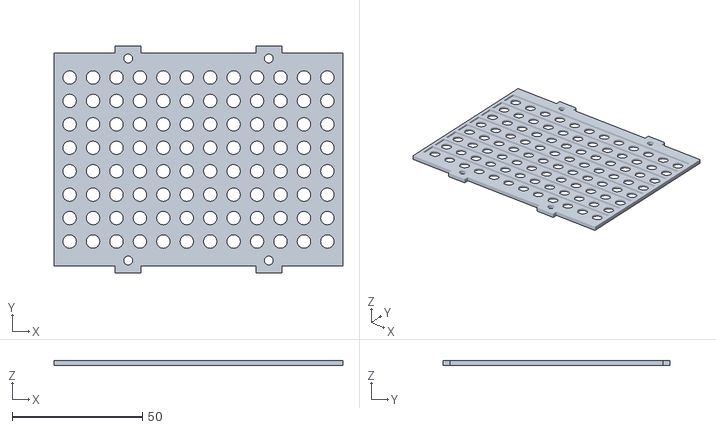
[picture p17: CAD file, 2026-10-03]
01_Hardware/ToPrint-STL/syringe_lock_frame.stl
111.0 x 87.0 x 2.00

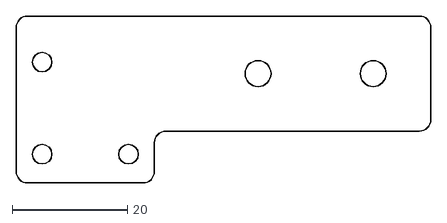
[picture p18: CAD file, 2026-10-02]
01_Hardware/ToLaserCut-DXF/lift_rail_plate.dxf
72.0 x 29.0

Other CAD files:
01_Hardware/ToPrint-STL/dshaft_lever.stl
01_Hardware/ToLaserCut-DXF/corner_bracket.dxf
01_Hardware/ToPrint-STL/tip_cone.stl
01_Hardware/ToLaserCut-DXF/lift_plate.dxf
01_Hardware/ToLaserCut-DXF/lift_base_plate.dxf
01_Hardware/ToLaserCut-DXF/pipette_plate.dxf
01_Hardware/ToLaserCut-DXF/plunger_carrier.dxf
01_Hardware/ToLaserCut-DXF/plunger_plate.dxf
01_Hardware/ToLaserCut-DXF/top_plate.dxf
01_Hardware/ToPrint-STL/control_box_base.stl
01_Hardware/ToPrint-STL/control_box_housing_sloped.stl
01_Hardware/ToPrint-STL/dshaft_trough_R.stl
01_Hardware/ToPrint-STL/head_bracket.stl
01_Hardware/ToPrint-STL/lift_carriage_bracket.stl
01_Hardware/ToPrint-STL/lift_home_switch_holder.stl
01_Hardware/ToPrint-STL/optical_switch_post.stl
01_Hardware/ToPrint-STL/pad_retainer.stl
01_Hardware/ToPrint-STL/plunger_carriage_bracket_RB_LF.stl
01_Hardware/ToPrint-STL/plunger_carriage_bracket_RF_LB.stl
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

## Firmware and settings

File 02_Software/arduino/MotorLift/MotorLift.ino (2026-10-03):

// Multi-channel pipette firmware for the motorized-lift layout (fixed head, lead-screw bed
// lift, belt-synced plunger). Pins, mechanics, speeds, calibration and labware are in Config.h.
//
// Menu (turn to move, press to select; a '*' marks a value being edited):
//   Volume      press, turn to set (1 uL steps below 20, 5 below 100, then 10), press to confirm
//   Aspirate    raise bed -> draw -> settle -> withdraw slowly -> lower bed
//   Dispense    Forward: dispense everything, blow out, withdraw, then reset the plunger
//               Reverse: dispense Volume (repeatable), keeping the excess in the tip
//   Mode        Forward (single transfers) / Reverse (repeat dispenses); only while empty
//   Labware     press to cycle presets (bed must be down)
//   Height      press, turn to trim the preset's working height by 0.1 mm (the bed follows
//               live if it is up), press to save to EEPROM
//   Raise/Lower bed (a manually raised bed stays up for Aspirate and reverse Dispense)
//   Empty tips  dispense everything held + blow out into the current labware (e.g. waste)
//   Eject tips  push the tips off onto whatever is on the bed (a waste tray, or the rack to return
//               them): plunger past home drives the ejector plate. Only with the bed down and the
//               tips empty; re-homes the plunger afterwards.
//   Cartridge   press to cycle the syringe cartridge fitted (tip capacity, calibration and tip
//               height come from its entry in CARTRIDGES); only with the tips empty and the bed
//               down; kept in EEPROM
//   Home all    re-home lift, then plunger. Shows "Homed, level 0.04" (spread of the plunger
//               switches in mm), or "Level: pin 11 late" if one switch closed more than
//               PLUNGER_TILT_MAX_MM after the first (plate tilted, e.g. a skipped belt tooth, or a
//               dead switch); the plunger then stays un-homed until Home all succeeds.
#include <Wire.h>
#include <EEPROM.h>
#include <LiquidCrystal_I2C.h>
#include "Config.h"

LiquidCrystal_I2C lcd(LCD_ADDR, 20, 4);

enum Item { ITEM_VOLUME, ITEM_ASPIRATE, ITEM_DISPENSE, ITEM_MODE, ITEM_LABWARE, ITEM_HEIGHT,
            ITEM_RAISE, ITEM_EMPTY, ITEM_EJECT, ITEM_CART, ITEM_HOME, ITEM_COUNT };

long volumeUl = 50;
bool reverseMode = false;
uint8_t labwareIdx = 0;
float heightTrim[LABWARE_COUNT];     // mm, per preset
uint8_t cartIdx = 0;                 // CARTRIDGES entry fitted
bool bedUp = false;

int8_t menuIdx = 0, menuTop = 0;
int8_t editItem = -1;                // item being edited with the knob, -1 = none
char statusMsg[19] = "";             // replaces the selected row's text until the next input
bool dirty = true;

const uint8_t EEPROM_MAGIC = 0xA8;   // bump if the stored layout changes

// ---------------------------------------------------------------- setup / loop
void setup() {
  lcd.init();
  lcd.backlight();
  pinMode(ENCODER_A_PIN, INPUT_PULLUP);
  pinMode(ENCODER_B_PIN, INPUT_PULLUP);
  pinMode(ENCODER_SW_PIN, INPUT_PULLUP);
  initMotors();
  loadTrims();
  homeAll();
}

void loop() {
  int8_t turn = 0;
  if (rotaryEncoder(turn)) onClick();
  if (turn) onTurn(turn);
  render();
}

// ---------------------------------------------------------------- calibration
// Commanded volume that delivers `wantUl`, by inverting a commanded->measured table
// (linear between points, extrapolated from the last segment).
float calCommand(const CalPoint *t, uint8_t n, float wantUl) {
  uint8_t i = 1;
  while (i < n - 1 && wantUl > t[i].measuredUl) i++;
  float m0 = t[i - 1].measuredUl, m1 = t[i].measuredUl;
  float c0 = t[i - 1].commandedUl, c1 = t[i].commandedUl;
  if (m1 == m0) return c0;
  return c0 + (wantUl - m0) * (c1 - c0) / (m1 - m0);
}

float commandFor(float wantUl) {
  const Cartridge &c = CARTRIDGES[cartIdx];
  if (reverseMode) return calCommand(c.calReverse, c.nReverse, wantUl);
  return calCommand(c.calForward, c.nForward, wantUl);
}

long tipCapacityUl() { return CARTRIDGES[cartIdx].capacityUl; }
float reverseExcessUl() { return CARTRIDGES[cartIdx].reverseExcessUl; }
float reversePreloadUl() { return CARTRIDGES[cartIdx].reversePreloadUl; }

// ---------------------------------------------------------------- bed
float engageMm() {
  float h = LABWARE[labwareIdx].engageMm + CARTRIDGES[cartIdx].tipOffsetMm + heightTrim[labwareIdx];
  return constrain(h, 0.0, LIFT_TRAVEL_MM);
}

bool raiseBed() {
  showStatus("Raising...");
  if (!moveLiftTo(engageMm(), LABWARE[labwareIdx].approachMmS, LIFT_FAST_MM_S)) {
    showStatus("Lift error: home");
    return false;
  }
  bedUp = true;
  return true;
}

// Leave the liquid slowly for the first WITHDRAW_MM, then drop to home (re-zeroing on it).
bool lowerBed() {
  showStatus("Lowering...");
  bool ok = moveLiftTo(liftMm() - WITHDRAW_MM, LIFT_FAST_MM_S, WITHDRAW_MM_S) && lowerLiftToHome();
  bedUp = false;
  if (!ok) showStatus("Lift error: home");
  return ok;
}

// ---------------------------------------------------------------- sequences
// Pin label for a plunger switch, as wired on the CNC shield (for status messages).
const char *swName(int8_t k) {
  static char buf[4];
  uint8_t pin = PLUNGER_SW_PINS[k];
  if (pin >= A0) snprintf(buf, sizeof(buf), "A%d", pin - A0);
  else snprintf(buf, sizeof(buf), "%d", pin);
  return buf;
}

void homeAll() {
  bedUp = false;
  showStatus("Homing lift...");
  if (!homeLift()) { showStatus("Lift home FAIL"); return; }
  showStatus("Homing plunger...");
  bool ok = homePlunger();
  char msg[19];
  if (plungerTiltMm < 0 && plungerLateSw >= 0) {     // a switch lagged the first by too much
    snprintf(msg, sizeof(msg), "Level: pin %s late", swName(plungerLateSw));
  } else if (!ok) {
    strcpy(msg, "Plunger home FAIL");
  } else {
    char mm[6];
    dtostrf(plungerTiltMm, 4, 2, mm);
    snprintf(msg, sizeof(msg), "Homed, level %s", mm);
  }
  showStatus(msg);
}

bool ready() {
  if (liftHomed && plungerHomed) return true;
  showStatus("Home all first");
  return false;
}

bool plungerFail() {
  showStatus("Plunger: home all");
  return false;
}

void runAspirate() {
  if (!ready()) return;
  float held = heldUl();
  // Draw the calibrated command (the same one the dispense uses). Reverse: plus the preload
  // (pushed back below), plus the excess if the tips are empty.
  float draw = commandFor(volumeUl);
  if (reverseMode) draw += reversePreloadUl() + (held < 0.5 ? reverseExcessUl() : 0);
  if (held + draw > tipCapacityUl()) { showStatus("Over tip capacity"); return; }
  bool stayUp = bedUp;
  if (!bedUp && !raiseBed()) return;
  for (uint8_t n = PREWET_CYCLES; n--;) {
    showStatus("Pre-wetting...");
    if (!plungerToHeld(held + draw, ASPIRATE_UL_S)) { plungerFail(); return; }
    delay(ASPIRATE_DELAY_MS);
    if (!plungerToHeld(held, DISPENSE_UL_S)) { plungerFail(); return; }
    delay(DISPENSE_DELAY_MS);
  }
  showStatus("Aspirating...");
  if (!plungerToHeld(held + draw, ASPIRATE_UL_S)) { plungerFail(); return; }
  delay(ASPIRATE_DELAY_MS);
  if (reverseMode) {                   // take up the slack in the dispense direction
    if (!plungerToHeld(held + draw - reversePreloadUl(), DISPENSE_UL_S)) { plungerFail(); return; }
    delay(DISPENSE_DELAY_MS);
  }
  if (!stayUp && !lowerBed()) return;
  showStatus("Aspirate DONE");
}

// Everything out at the current labware: dispense to the working zero, blow out, withdraw,
// and only then return the plunger (it draws air on the way back up).
bool dispenseAll(const char *doneMsg) {
  if (!bedUp && !raiseBed()) return false;
  showStatus("Dispensing...");
  if (!plungerToHeld(0, DISPENSE_UL_S)) return plungerFail();
  delay(DISPENSE_DELAY_MS);
  showStatus("Blowing out...");
  if (!plungerBlowout()) return plungerFail();
  delay(BLOWOUT_DELAY_MS);
  if (!lowerBed()) return false;
  if (!plungerReset()) return plungerFail();
  showStatus(doneMsg);
  return true;
}

void runDispense() {
  if (!ready()) return;
  float held = heldUl();
  if (held < 0.5) { showStatus("Nothing held"); return; }
  if (!reverseMode) { dispenseAll("Dispense DONE"); return; }
  float cmd = commandFor(volumeUl);
  if (held - cmd < reverseExcessUl() - 0.05) { showStatus("Low: Empty tips"); return; }
  bool stayUp = bedUp;
  if (!bedUp && !raiseBed()) return;
  showStatus("Dispensing...");
  if (!plungerToHeld(held - cmd, DISPENSE_UL_S)) { plungerFail(); return; }
  delay(DISPENSE_DELAY_MS);
  if (!stayUp && !lowerBed()) return;
  showStatus("Dispense DONE");
}

void runEject() {
  if (!ready()) return;
  if (bedUp) { showStatus("Lower bed first"); return; }
  if (heldUl() >= 0.5) { showStatus("Empty tips first"); return; }
  showStatus("Ejecting tips...");
  if (!plungerEject()) { showStatus("Eject: home FAIL"); return; }
  showStatus("Tips ejected");
}

void runEmpty() {
  if (!ready()) return;
  if (heldUl() < 0.5) { showStatus("Tips are empty"); return; }
  dispenseAll("Tips emptied");
}

// ---------------------------------------------------------------- input
long volumeStep(long v) { return v < 20 ? 1 : (v < 100 ? 5 : 10); }

void onClick() {
  statusMsg[0] = '\0';
  switch (menuIdx) {
    case ITEM_VOLUME:
      editItem = (editItem == ITEM_VOLUME) ? -1 : ITEM_VOLUME;
      break;
    case ITEM_HEIGHT:
      if (editItem == ITEM_HEIGHT) { editItem = -1; saveTrims(); showStatus("Height saved"); }
      else editItem = ITEM_HEIGHT;
      break;
    case ITEM_MODE:
      if (heldUl() >= 0.5) showStatus("Empty tips first");
      else reverseMode = !reverseMode;
      break;
    case ITEM_LABWARE:
      if (bedUp) showStatus("Lower bed first");
      else labwareIdx = (labwareIdx + 1) % LABWARE_COUNT;
      break;
    case ITEM_ASPIRATE: runAspirate(); break;
    case ITEM_DISPENSE: runDispense(); break;
    case ITEM_RAISE:
      if (!ready()) break;
      if (bedUp) { if (lowerBed()) showStatus("Bed down"); }
      else if (raiseBed()) showStatus("Bed up");
      break;
    case ITEM_EMPTY: runEmpty(); break;
    case ITEM_EJECT: runEject(); break;
    case ITEM_CART:
      if (heldUl() >= 0.5) showStatus("Empty tips first");
      else if (bedUp) showStatus("Lower bed first");
      else {
        cartIdx = (cartIdx + 1) % CARTRIDGE_COUNT;
        volumeUl = constrain(volumeUl, VOLUME_MIN_UL, tipCapacityUl());
        saveTrims();
      }
      break;
    case ITEM_HOME: homeAll(); break;
  }
  dirty = true;
}

void onTurn(int8_t d) {
  statusMsg[0] = '\0';
  if (editItem == ITEM_VOLUME) {
    long v = volumeUl + (d > 0 ? volumeStep(volumeUl) : -volumeStep(volumeUl - 1));
    volumeUl = constrain(v, VOLUME_MIN_UL, tipCapacityUl());
  } else if (editItem == ITEM_HEIGHT) {
    float base = LABWARE[labwareIdx].engageMm;
    float t = heightTrim[labwareIdx] + d * HEIGHT_STEP_MM;
    heightTrim[labwareIdx] = constrain(base + t, 0.0, LIFT_TRAVEL_MM) - base;
    if (bedUp) moveLiftTo(engageMm(), LABWARE[labwareIdx].approachMmS, LIFT_FAST_MM_S);   // follow live
  } else {
    menuIdx = (menuIdx + d + ITEM_COUNT) % ITEM_COUNT;
    if (menuIdx < menuTop) menuTop = menuIdx;
    if (menuIdx > menuTop + 3) menuTop = menuIdx - 3;
  }
  dirty = true;
}

// ---------------------------------------------------------------- display
void showStatus(const char *msg) {
  strncpy(statusMsg, msg, sizeof(statusMsg) - 1);
  statusMsg[sizeof(statusMsg) - 1] = '\0';
  dirty = true;
  render();                         // visible during blocking moves
}

void rowText(int8_t item, char *buf) {
  char sel = ' ';
  if (item == menuIdx) sel = (editItem == item) ? '*' : '>';
  char num[8];
  if (item == menuIdx && statusMsg[0]) {
    snprintf(buf, 21, "%c %s", sel, statusMsg);
  } else switch (item) {
    case ITEM_VOLUME:   snprintf(buf, 21, "%c Volume    %4ld uL", sel, volumeUl); break;
    case ITEM_ASPIRATE: snprintf(buf, 21, "%c Aspirate", sel); break;
    case ITEM_DISPENSE: snprintf(buf, 21, "%c Dispense  held %3ld", sel, lround(heldUl())); break;
    case ITEM_MODE:     snprintf(buf, 21, "%c Mode: %s", sel, reverseMode ? "Reverse" : "Forward"); break;
    case ITEM_LABWARE:  snprintf(buf, 21, "%c %s", sel, LABWARE[labwareIdx].name); break;
    case ITEM_HEIGHT:
      dtostrf(engageMm(), 5, 1, num);
      snprintf(buf, 21, "%c Height   %s mm", sel, num);
      break;
    case ITEM_RAISE:    snprintf(buf, 21, "%c %s", sel, bedUp ? "Lower bed" : "Raise bed"); break;
    case ITEM_EMPTY:    snprintf(buf, 21, "%c Empty tips", sel); break;
    case ITEM_EJECT:    snprintf(buf, 21, "%c Eject tips", sel); break;
    case ITEM_CART:     snprintf(buf, 21, "%c Cart %s", sel, CARTRIDGES[cartIdx].name); break;
    case ITEM_HOME:     snprintf(buf, 21, "%c Home all", sel); break;
    default:            buf[0] = '\0';
  }
  size_t n = strlen(buf);                      // pad so old characters are overwritten
  while (n < 20) buf[n++] = ' ';
  buf[20] = '\0';
}

void render() {
  if (!dirty) return;
  char buf[21];
  for (uint8_t r = 0; r < 4; r++) {
    rowText(menuTop + r, buf);
    lcd.setCursor(0, r);
    lcd.print(buf);
  }
  dirty = false;
}

// ---------------------------------------------------------------- EEPROM (height trims, cartridge)
const int EEPROM_CART_ADDR = 1 + LABWARE_COUNT * sizeof(float);

void loadTrims() {
  if (EEPROM.read(0) != EEPROM_MAGIC) {
    for (uint8_t i = 0; i < LABWARE_COUNT; i++) heightTrim[i] = 0;
    cartIdx = 0;
    return;
  }
  for (uint8_t i = 0; i < LABWARE_COUNT; i++) {
    EEPROM.get(1 + i * sizeof(float), heightTrim[i]);
    if (isnan(heightTrim[i]) || fabs(heightTrim[i]) > LIFT_TRAVEL_MM) heightTrim[i] = 0;
  }
  cartIdx = EEPROM.read(EEPROM_CART_ADDR);
  if (cartIdx >= CARTRIDGE_COUNT) cartIdx = 0;
}

void saveTrims() {
  EEPROM.update(0, EEPROM_MAGIC);
  for (uint8_t i = 0; i < LABWARE_COUNT; i++) EEPROM.put(1 + i * sizeof(float), heightTrim[i]);
  EEPROM.update(EEPROM_CART_ADDR, cartIdx);
}

// ---------------------------------------------------------------- encoder (from the original)
bool rotaryEncoder(int8_t &delta) {
  delta = 0;
  enum {STATE_LOCKED, STATE_TURN_RIGHT_START, STATE_TURN_RIGHT_MIDDLE, STATE_TURN_RIGHT_END,
        STATE_TURN_LEFT_START, STATE_TURN_LEFT_MIDDLE, STATE_TURN_LEFT_END, STATE_UNDECIDED};
  static uint8_t encoderState = STATE_LOCKED;

  bool a = !digitalRead(ENCODER_A_PIN);
  bool b = !digitalRead(ENCODER_B_PIN);
  bool s = !digitalRead(ENCODER_SW_PIN);

  static bool switchState = s;

  switch (encoderState) {
    case STATE_LOCKED:
      if (a && b) encoderState = STATE_UNDECIDED;
      else if (!a && b) encoderState = STATE_TURN_LEFT_START;
      else if (a && !b) encoderState = STATE_TURN_RIGHT_START;
      else encoderState = STATE_LOCKED;
      break;

    case STATE_TURN_RIGHT_START:
      if (a && b) encoderState = STATE_TURN_RIGHT_MIDDLE;
      else if (!a && b) encoderState = STATE_TURN_RIGHT_END;
      else if (a && !b) encoderState = STATE_TURN_RIGHT_START;
      else { encoderState = STATE_LOCKED; }
      break;

    case STATE_TURN_RIGHT_MIDDLE:
    case STATE_TURN_RIGHT_END:
      if (a && b) encoderState = STATE_TURN_RIGHT_MIDDLE;
      else if (!a && b) encoderState = STATE_TURN_RIGHT_END;
      else if (a && !b) encoderState = STATE_TURN_RIGHT_START;
      else { encoderState = STATE_LOCKED; delta = -1; }
      break;

    case STATE_TURN_LEFT_START:
      if (a && b) encoderState = STATE_TURN_LEFT_MIDDLE;
      else if (!a && b) encoderState = STATE_TURN_LEFT_START;
      else if (a && !b) encoderState = STATE_TURN_LEFT_END;
      else { encoderState = STATE_LOCKED; }
      break;

    case STATE_TURN_LEFT_MIDDLE:
    case STATE_TURN_LEFT_END:
      if (a && b) encoderState = STATE_TURN_LEFT_MIDDLE;
      else if (!a && b) encoderState = STATE_TURN_LEFT_START;
      else if (a && !b) encoderState = STATE_TURN_LEFT_END;
      else { encoderState = STATE_LOCKED; delta = 1; }
      break;

    case STATE_UNDECIDED:
      if (a && b) encoderState = STATE_UNDECIDED;
      else if (!a && b) encoderState = STATE_TURN_RIGHT_END;
      else if (a && !b) encoderState = STATE_TURN_LEFT_END;
      else encoderState = STATE_LOCKED;
      break;
  }

  // simple debounce for switch
  uint32_t current_time = millis();
  static uint32_t switch_time = 0;
  const uint32_t bounce_time = 30;
  bool back = false;
  if (current_time - switch_time >= bounce_time) {
    if (switchState != s) {
      switch_time = current_time;
      back = s;
      switchState = s;
    }
  }
  return back;
}

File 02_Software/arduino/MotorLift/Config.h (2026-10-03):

// Configuration for the motorized-lift layout: fixed pipette head, lead-screw bed lift,
// belt-synced plunger (one motor drives all four plunger screws).
//
// Hardware: Arduino Uno + CNC Shield V3, 20x4 I2C LCD, rotary encoder with push switch.
//   X slot -> plunger motor      Y slot -> lift motor      Z and A slots -> unused
// Set each driver's microstepping jumpers to match *_MICROSTEPS below.
#pragma once
#include <Arduino.h>

// ---------------------------------------------------------------- pins (CNC Shield V3)
const uint8_t EN_PIN           = 8;    // shared driver enable, LOW = enabled
const uint8_t PLUNGER_STEP_PIN = 2;    // X
const uint8_t PLUNGER_DIR_PIN  = 5;
const uint8_t LIFT_STEP_PIN    = 3;    // Y
const uint8_t LIFT_DIR_PIN     = 6;

// Home sensors, read with INPUT_PULLUP. The plunger uses three slotted optical endstops on the
// original corner-switch inputs (X-, Z-, CoolEn), each with a flag on the plunger plate: optical,
// because the plate carries on past home to eject tips. The first to trigger sets home, since the
// belt keeps the plate level, and homing checks that the other two follow within
// PLUNGER_TILT_MAX_MM (a belt that skipped a tooth on one screw tilts the plate). The fourth
// original input, Y-, is the lift's home switch (a lever switch to GND: LOW = pressed).
const uint8_t PLUNGER_SW_PINS[] = {9, 11, A3};
// Level the optical endstops output when the flag blocks the beam. Most endstop boards for 3D
// printers read HIGH when blocked, so a missing or unplugged sensor also reads "blocked" and
// homing fails safe ("stuck"). Check yours with a flag and a multimeter.
const uint8_t PLUNGER_SW_ACTIVE = HIGH;
const uint8_t PLUNGER_SW_COUNT  = sizeof(PLUNGER_SW_PINS) / sizeof(PLUNGER_SW_PINS[0]);
const uint8_t LIFT_SW_PIN       = 10;

// UI (unchanged from the original build). D0/D1 are the serial pins: if an upload fails,
// turn the encoder a few clicks or unplug it during the upload.
const uint8_t ENCODER_A_PIN = 0;
const uint8_t ENCODER_B_PIN = 1;
const uint8_t ENCODER_SW_PIN = A1;
const uint8_t LCD_ADDR = 0x27;

// ---------------------------------------------------------------- directions
// Flip these if an axis moves the wrong way (depends on motor wiring and mounting).
const uint8_t PLUNGER_DISPENSE_LEVEL = HIGH;   // DIR level that moves the plunger plate down
const uint8_t LIFT_UP_LEVEL          = HIGH;   // DIR level that raises the bed

// ---------------------------------------------------------------- mechanics
const uint16_t MOTOR_STEPS        = 200;   // 1.8 deg steppers
const uint8_t  PLUNGER_MICROSTEPS = 8;     // X-slot jumpers
const uint8_t  LIFT_MICROSTEPS    = 8;     // Y-slot jumpers
const float    PLUNGER_LEAD_MM    = 2.0;   // T8x2 with anti-backlash nuts
const float    LIFT_LEAD_MM       = 2.0;   // T8x2

// The original firmware used 12 steps/uL with T8x8 screws (8 mm lead) at the same
// microstepping; that scales with the lead. Refine with the calibration tables below.
const float PLUNGER_STEPS_PER_UL = 12.0 * (8.0 / PLUNGER_LEAD_MM);   // 48
const float PLUNGER_STEPS_PER_MM = MOTOR_STEPS * (float)PLUNGER_MICROSTEPS / PLUNGER_LEAD_MM;   // 800
const float LIFT_STEPS_PER_MM    = MOTOR_STEPS * (float)LIFT_MICROSTEPS / LIFT_LEAD_MM;

const float LIFT_TRAVEL_MM = 66.0;         // soft limit above home (Blender model: 65.9 mm)

// ---------------------------------------------------------------- tips and volumes
const long  VOLUME_MIN_UL   = 1;
// Volume knob steps: 1 uL below 20, 5 uL below 100, 10 uL above.

// The working zero ("first stop") sits BLOWOUT_UL above the switches ("second stop"): a
// forward dispense ends at the working zero, then blows out down to the switches.
const float BLOWOUT_UL = 10.0;

// Extra steps added whenever the plunger reverses direction. Anti-backlash nuts should make
// this ~0; measure by reversing and watching the plate with a dial indicator.
const float BACKLASH_UL = 0.0;

// ---------------------------------------------------------------- cartridges and calibration
// Measured volume for a commanded volume, per mode (0 must map to 0; keep it increasing).
// Weigh water dispensed at several volumes (1 uL = 1 mg at room temperature; ISO 8655
// describes the method) and enter commanded -> measured pairs. Identity until measured.
// Each syringe cartridge has its own syringes, so each gets its own tables.
struct CalPoint { float commandedUl; float measuredUl; };
const CalPoint CAL_200_FORWARD[] = {{0, 0}, {200, 200}};
const CalPoint CAL_200_REVERSE[] = {{0, 0}, {200, 200}};
const CalPoint CAL_10_FORWARD[]  = {{0, 0}, {10, 10}};
const CalPoint CAL_10_REVERSE[]  = {{0, 0}, {10, 10}};
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

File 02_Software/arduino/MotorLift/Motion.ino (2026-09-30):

// Stepper motion for the lift (Y) and the belt-synced plunger (X).
// Positions are tracked in steps from each axis's home switch.

long liftPos = 0;          // steps above home
long plungerPos = 0;       // steps above the switches ("second stop"); see plungerWorkZero()
int8_t plungerLastDir = 0; // +1 up, -1 down, 0 unknown (for backlash compensation)
bool liftHomed = false;
bool plungerHomed = false;
float plungerTiltMm = -1;
int8_t plungerLateSw = -1;

void initMotors() {
  pinMode(EN_PIN, OUTPUT);
  digitalWrite(EN_PIN, LOW);
  pinMode(PLUNGER_STEP_PIN, OUTPUT);
  pinMode(PLUNGER_DIR_PIN, OUTPUT);
  pinMode(LIFT_STEP_PIN, OUTPUT);
  pinMode(LIFT_DIR_PIN, OUTPUT);
  for (uint8_t i = 0; i < PLUNGER_SW_COUNT; i++) pinMode(PLUNGER_SW_PINS[i], INPUT_PULLUP);
  pinMode(LIFT_SW_PIN, INPUT_PULLUP);
}

bool liftSwitch() {
  return digitalRead(LIFT_SW_PIN) == LOW;
}

bool plungerSwitch() {
  for (uint8_t i = 0; i < PLUNGER_SW_COUNT; i++)
    if (digitalRead(PLUNGER_SW_PINS[i]) == PLUNGER_SW_ACTIVE) return true;
  return false;
}

bool plungerClear() { return !plungerSwitch(); }

// (No `static` on these helpers: the Arduino IDE's prototype generator mishandles it.)

// Step one axis `steps` times with a trapezoidal speed profile (David Austin's step-interval
// recurrence, no per-step sqrt). If stopCheck is given, stop once it has read true on three
// consecutive steps. Returns the number of steps taken.
long stepAxis(uint8_t stepPin, uint8_t dirPin, uint8_t dirLevel, long steps,
              float vmax, float accel, bool (*stopCheck)()) {
  if (steps <= 0) return 0;
  digitalWrite(dirPin, dirLevel);
  delayMicroseconds(5);                         // DIR setup time

  const float cMin = 1e6 / vmax;                // us per step at full speed
  float c = 0.676 * sqrt(2.0 / accel) * 1e6;    // first interval
  if (c < cMin) c = cMin;
  long n = 0;                                   // steps spent accelerating
  uint8_t hits = 0;
  uint32_t next = micros();

  for (long i = 0; i < steps; i++) {
    while ((long)(micros() - next) < 0) {}
    digitalWrite(stepPin, HIGH);
    delayMicroseconds(3);
    digitalWrite(stepPin, LOW);

    if (stopCheck) {
      hits = stopCheck() ? hits + 1 : 0;
      if (hits >= 3) return i + 1;
    }

    long remaining = steps - i - 1;
    if (remaining <= n) {                       // decelerate symmetrically
      if (remaining > 0) c = c + 2.0 * c / (4.0 * remaining - 1.0);
    } else if (c > cMin) {                      // accelerate
      n++;
      c = c - 2.0 * c / (4.0 * n + 1.0);
      if (c < cMin) c = cMin;
    }
    next += (uint32_t)c;
  }
  while ((long)(micros() - next) < 0) {}        // hold the last interval so back-to-back moves don't jerk
  return steps;
}

// ---------------------------------------------------------------- lift
float liftMm() { return liftPos / LIFT_STEPS_PER_MM; }

long liftUp(long steps, float mmS) {
  return stepAxis(LIFT_STEP_PIN, LIFT_DIR_PIN, LIFT_UP_LEVEL, steps,
                  mmS * LIFT_STEPS_PER_MM, LIFT_ACCEL_MM_S2 * LIFT_STEPS_PER_MM, nullptr);
}

long liftDown(long steps, float mmS, bool stopAtSwitch) {
  return stepAxis(LIFT_STEP_PIN, LIFT_DIR_PIN, !LIFT_UP_LEVEL, steps,
                  mmS * LIFT_STEPS_PER_MM, LIFT_ACCEL_MM_S2 * LIFT_STEPS_PER_MM,
                  stopAtSwitch ? liftSwitch : nullptr);
}

// Down to the switch fast, back off, re-approach slowly; home is where the switch closes.
bool homeLift() {
  liftHomed = false;
  const long backoff = LIFT_BACKOFF_MM * LIFT_STEPS_PER_MM;
  if (liftSwitch()) liftUp(backoff, LIFT_HOME_FAST_MM_S);
  const long maxSteps = (LIFT_TRAVEL_MM + 5) * LIFT_STEPS_PER_MM;
  liftDown(maxSteps, LIFT_HOME_FAST_MM_S, true);
  if (!liftSwitch()) return false;
  liftUp(backoff, LIFT_HOME_FAST_MM_S);
  if (liftSwitch()) return false;               // switch stuck closed
  liftDown(2 * backoff, LIFT_HOME_SLOW_MM_S, true);
  if (!liftSwitch()) return false;
  liftPos = 0;
  liftHomed = true;
  return true;
}

// Rise to `mm` (fast, then the last LIFT_SEAT_ZONE_MM at approachMmS), or descend at downMmS.
bool moveLiftTo(float mm, float approachMmS, float downMmS) {
  if (!liftHomed) return false;
  if (mm < 0) mm = 0;
  if (mm > LIFT_TRAVEL_MM) mm = LIFT_TRAVEL_MM;
  long target = lround(mm * LIFT_STEPS_PER_MM);
  if (target <= 0) return lowerLiftToHome();
  if (target > liftPos) {
    long seatStart = target - (long)(LIFT_SEAT_ZONE_MM * LIFT_STEPS_PER_MM);
    if (seatStart > liftPos) liftPos += liftUp(seatStart - liftPos, LIFT_FAST_MM_S);
    liftPos += liftUp(target - liftPos, approachMmS);
  } else if (target < liftPos) {
    long moved = liftDown(liftPos - target, downMmS, true);
    liftPos -= moved;
    if (liftSwitch()) {                          // hit home early: steps were lost going up
      liftPos = 0;
      return false;
    }
  }
  return true;
}

// Lower to home and re-zero on the switch every time, so lost steps never accumulate.
bool lowerLiftToHome() {
  if (!liftHomed) return false;
  if (liftPos > 0) liftDown(liftPos, LIFT_FAST_MM_S, true);
  if (!liftSwitch()) {                           // not there yet: creep down up to 3 mm
    liftDown(3 * LIFT_STEPS_PER_MM, LIFT_HOME_SLOW_MM_S, true);
    if (!liftSwitch()) { liftHomed = false; return false; }
  }
  liftPos = 0;
  return true;
}

// ---------------------------------------------------------------- plunger
// Positions are steps above the switches. The working zero ("first stop") is BLOWOUT_UL above
// them; "held" is liquid (and, in reverse mode, excess) drawn above the working zero.
const long PLUNGER_BACKLASH_STEPS = lround(BACKLASH_UL * PLUNGER_STEPS_PER_UL);
const float PLUNGER_ACCEL_STEPS_S2 = PLUNGER_ACCEL_UL_S2 * PLUNGER_STEPS_PER_UL;

long plungerWorkZero() { return lround(BLOWOUT_UL * PLUNGER_STEPS_PER_UL); }

float heldUl() {
  long h = plungerPos - plungerWorkZero();
  return h > 0 ? h / PLUNGER_STEPS_PER_UL : 0;
}

long plungerUp(long steps, float ulPerS) {
  return stepAxis(PLUNGER_STEP_PIN, PLUNGER_DIR_PIN, !PLUNGER_DISPENSE_LEVEL, steps,
                  ulPerS * PLUNGER_STEPS_PER_UL, PLUNGER_ACCEL_STEPS_S2, nullptr);
}

long plungerDown(long steps, float ulPerS) {
  return stepAxis(PLUNGER_STEP_PIN, PLUNGER_DIR_PIN, PLUNGER_DISPENSE_LEVEL, steps,
                  ulPerS * PLUNGER_STEPS_PER_UL, PLUNGER_ACCEL_STEPS_S2, plungerSwitch);
}
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

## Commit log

2026-09-29 Add MotorLift firmware for the motorized bed-lift layout
    New sketch for the redesigned machine: fixed pipette head, lead-screw bed
    lift, and one belt-synced plunger motor. The original Combined sketch is
    unchanged.
    - Plunger on the X slot, lift on Y; Z and A are freed.
    - Homes the lift (down) before the plunger, since plunger homing dispenses.
    - Trapezoidal step profiles; the lift slows for the last 4 mm of a rise.
    - The lift re-zeros on its switch every time it lowers, so lost steps
    don't accumulate.
    - Labware presets with 0.1 mm height trims saved to EEPROM, a live height
    adjust while the bed is up, and capacity/empty guards.
    Checked with a host-side simulation (32 checks) and compil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
    [Config.h, Motion.ino, MotorLift.ino]
2026-09-29 Add Blender build scripts for the original design and two redesigns
    04_Blender holds scripts that rebuild the machine in Blender 5.2 from the
    STL/DXF parts in 01_Hardware:
    - build_pipette.py: the original design (lever lowers the head).
    - variant_raise_bed.py: fixed head, geared toggle lever raises the bed.
    - variant_motor_lift.py: fixed head, motorized T8x2 lift and a
    belt-synced plunger, with idler tensioners and a lift home switch
    (the layout the MotorLift firmware targets).
    Paths resolve relative to the script, so they run with
    `blender --python 04_Blender/<script>.py` or from Blender's Text Editor.
    Both variants keyframe a full cycle and include a collision sweep; both
    sweeps repo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
2026-09-29 Improve plunger accuracy: T8x2 drive, blow-out, reverse mode, calibration
    Firmware (MotorLift):
    - Plunger on T8x2 screws with anti-backlash nuts: 48 steps/uL, scaled
    from the original 12 steps/uL on T8x8.
    - Volumes capped at the 200 uL tip capacity (was 990 uL, which would
    pull liquid into the barrels); 1 uL knob steps below 20 uL.
    - Working zero sits 10 uL above the switches. Forward mode dispenses,
    blows out to the switches, withdraws, and only then resets the plunger
    so it draws air, not liquid.
    - Reverse mode draws extra and pushes a little back so the nut's slack is
    taken up in the dispense direction; repeat dispenses are then exact.
    "Empty tips" discards the remainder.
    - Pe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
    [Config.h, Motion.ino, MotorLift.ino]
2026-09-29 Add fabrication files for the motorized-lift build and a parts list
    01_Hardware/MotorLift holds the cut and print files for every part that is
    new or changed in this layout:
    - make_dxf.py: the layout numbers (screw, motor, switch, bracket positions)
    and a generator for the laser-cut DXFs: modified pipette and plunger
    plates, plus the new lift platform and lift base plate.
    - ToPrint-STL: modified plunger holder plate, head brackets, both belt
    tensioner brackets and the lift home-switch holder, oriented for printing.
    Designing the real parts exposed a few gaps in the model, now fixed:
    - The pipette plate's "fixed mounts" were placeholders sitting on the
    rails. It now bolts through pri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
    [head_bracket.stl, lift_base_plate.dxf, lift_home_switch_holder.stl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]
2026-09-29 Move the control box in front of the base
    The electronics housing now lies in front of the base with the screen and
    knob facing up and the lid on the bench, instead of standing on the front
    face at the top. At about 76 mm tall (knob 88.5 mm) it stays below the
    lowered tray at 96 mm, so well plates still slide in from the front over
    it. It fixes to the bottom front bar with two screws through its back
    wall, and it now sits next to the lift motor.
    Collision sweep still clean. Added a control-box render and refreshed the
    side views; BOM and README note the new placement.
2026-09-29 Slope the control box's screen panel 10 degrees toward the user
    The housing's screen panel now tilts toward the front, lowering the front
    wall from 76.5 to 59 mm while the back keeps its full height
    (CONTROL_SLOPE_DEG in variant_motor_lift.py).
    The LCD, encoder and Arduino mount on standoffs under the panel, so the
    panel and everything within 7.5 mm under it tilt as one rigid piece
    about the back top edge, and the boards keep their mounting. The walls
    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
    [control_box_housing_sloped.stl]
2026-09-29 Mount the T8 nuts through cloverleaf cutouts
    Each T8 nut in the lift and plunger plates used a center bore with four
    separate M3 holes, which left only 1.2 mm (lift) and 1.9 mm (plunger) of
    steel between them, under the 3 mm plate thickness most laser shops
    accept. The nut now mounts through one cutout: the bore with four 3.4 mm
    slots out to the flange screws. The flange covers the slots and carries
    the load; a washer under each M3 nut spans its slot.
    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
    [lift_plate.dxf, plunger_plate_motorlift.dxf]
2026-09-29 Set the viewport clip range and start view on every screen
    stage() only set the active screen's viewport, and there is none under
    blender -b, so .blend files built headless opened with Blender's default
    0.01-1000 clip range. At mm-as-unit scale that clipped the far side of the
    model when zoomed out and caused z-fighting. Every 3D view now gets a
    1-20000 clip range, material preview, and a start view matching the
    render camera.
2026-09-29 Replace the lift platform's corner blocks with carriage brackets
    The four blocks on the lift platform were copies of the repo's
    LimitSwitch_holder_A, a limit-switch holder, and held no switch. They
    also joined nothing: the steel plate stopped 1.6 mm short of the rail
    plates, and the rail plates' M4 holes lined up with the plate's 3 mm edge.
    A printed carriage bracket at each corner now joins the platform to its
    rail plate: 2 M4 in through the rail plate's own holes into captive nuts,
    and 2 M4 down through counterbores and the platform (8 new holes in
    lift_plate.dxf, LIFT_BRACKET_* in make_dxf.py). The rail plates and
    carriages ride 11.5 mm higher so their M4 row clears the plate. The
    bracke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
    [lift_carriage_bracket.stl, lift_plate.dxf]
2026-09-29 Replace the plunger plate's corner blocks with carriage brackets
    The plunger plate had the same fault as the lift platform: its four
    LimitSwitch_holder_A copies held no switch (the plunger homes on the
    pipette-level switches) and sat where the printed holder plate is, and
    nothing joined the plate to its rail plates, which stood 6.6 mm off its
    edge with their M4 holes on the plate's 3 mm edge.
    A printed carriage bracket now hangs under each side edge of the plunger
    plate, between the syringe array and the nut screws: 2 M4 down through
    the plate into captive nuts, and 2 M4 in from outside through the rail
    plate into captive nuts. The upstream rail plate's arm doesn't reach
    down to the bracket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
    [plunger_carriage_bracket_RB_LF.stl, plunger_carriage_bracket_RF_LB.stl, plunger_holder_plate_motorlift.stl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]
2026-09-29 Fasten every part that the model only placed
    An audit of the whole model (which parts touch, and whether each joint
    has fasteners with matching holes in both parts) found parts placed from
    the build video that were attached to nothing:
    - Plunger home switches: the repo corner blocks stood on their sides,
    unbolted, and there were four though the firmware uses three. Three
    printed switch posts now bolt to the pipette plate (2 M3 each).
    - Stiffening frame: it only rested on the printed holder plate. The long
    bars move to y +/-32 and are clamped at both ends by the plunger
    bracket bolts (M4 into T-nuts); the short bars move to x +/-60 (44 mm)
    with one M5 up through both plates at mid-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
    [control_box_base.stl, control_box_housing_sloped.stl, lift_plate.dxf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]
2026-09-29 Check that the plunger plate is level when homing
    One belt drives all four plunger screws, so the plate stays level unless
    the belt skips a tooth on one screw's pulley, which drops that corner by
    0.1 mm (2 mm lead, 20 teeth). The homing used to stop at the first of
    the three switches, so it could not notice.
    The slow final approach now keeps going after the first switch closes,
    until the other two have closed or the plate has moved
    PLUNGER_TILT_MAX_MM further, and records where each closed. Home is
    still where the first switch closed. The LCD shows the spread ("Homed,
    level 0.04"); if a switch closes too late or not at all it shows
    "Level: pin 11 late" and the plunger stays un-homed until H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
    [Config.h, Motion.ino, MotorLift.ino]
2026-09-29 Key the syringe flanges under a locking frame instead of press-fitting
    Suggested in a comment on the build video: instead of cutting the
    flanged end off each syringe and hammering the barrels into the grip,
    trim the finger tabs to stubs and use them to seat the barrels.
    Each flange (tabs trimmed to 8.2 mm across, at most 7.2 mm wide) now
    sits on the pipette plate in a per-row slot on the underside of a new
    printed locking frame, 0.1 mm shallower than the flange so every flange
    is clamped down and the stubs cannot turn. The frame replaces the repo
    S-P plate and is held by the head-bracket M4s that already come up
    through the plate. The repo grip's holes open from 6.5 to 6.9 mm so it
    only gui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
    [syringe_grip_slipfit.stl, syringe_lock_frame.stl]
2026-09-29 Move the control box's USB port to its left end
    The repo housing hung on the frame with its USB opening facing down.
    Laid in front of the base, that wall faces the user, so the cable would
    stick out toward them and the plate-loading path. The front opening is
    now filled, and a panel-mount USB-B socket goes in the left end, beside
    the existing DC jack, joined to the Arduino by a short USB-B extension,
    so the board and its standoffs stay where they are.
    The cutout (12.5 x 11.5 mm, M3 ears 30 mm apart) is a typical socket
    size, set by USB_PANEL_* in variant_motor_lift.py; check it against the
    socket bought. Housing re-exported (watertight), collision sweep clean.
    Added the extension and its sc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
    [control_box_housing_sloped.stl]
2026-09-29 Add a tip ejector driven by the plunger going past home
    Tips could only be pulled off by hand. Like a hand pipette's third stop,
    the plunger now goes on past home to eject them.
    - A 3 mm laser-cut plate (tip_ejector_plate.dxf) sits under the barrel
    ends with a 5.8 mm hole around each nozzle. Springs on its 4 M4 rods
    hold it up against the barrels, where it is also the stop the tips
    seat against. The tips sit 5 mm lower to make room, so the lift
    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
    [optical_switch_post.stl, pipette_plate_motorlift.dxf, plunger_flag.stl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]
2026-09-30 Make the syringes a cartridge that slides in at the front like a drawer
    Everything that depends on the syringes and tips is now one unit, so a
    machine can carry cartridges for different tip families and swap them
    (or a spare) without tools: open two levers, pull the drawer out by its
    handle, slide the other in until it clicks, close the levers.
    Machine side:
    - The plunger drive moves to a new top plate on the frame's top ring
    (top_plate.dxf): the screws hang from KFL08s on it, the pulleys, belt
    and idler run under it inside the ring, and the motor stands on it.
    That clears the head for the drawer.
    - The pipette plate is redrawn as a U open at the front. Steel ledges
    (cart_ledge.dxf)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
    [cart_ledge.dxf, cart_spacer_R.stl, cartridge_handle.stl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]
2026-09-30 Add cartridge profiles to the firmware
    A "Cartridge" menu item picks the syringe cartridge fitted. Each entry
    in CARTRIDGES (Config.h) has its tip capacity, its own forward and
    reverse calibration tables, and a tip height offset added to every
    labware height; the choice is kept in EEPROM (layout bumped, so the
    first boot after updating resets the height trims) and can only change
    with the tips empty and the bed down. The 10 uL entry is a placeholder:
    its offset stays 0, the safe side, until the tips are measured.
    The lift travel and the 96-well height drop 3 mm to 38 / 37.9 mm, since
    the tips now sit under the cartridge plate.
    Compiles for the Uno; host tests pass (59 checks, including cap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
    [Config.h, Motion.ino, MotorLift.ino]
2026-09-30 Make the drawer levers clamp for real, animate the swap, move the plunger motor to the back
    The D-shaft levers didn't touch their shafts and the shafts had no flat, so
    turning them did nothing. The shafts now have the 0.8 mm flat (facing out
    when clamped). Each lever is pinned across its shaft with a 2 x 16 mm spring
    pin. Its hub is trimmed flush with the flat and its arm is 5.6 mm thick, so
    with the lever open the carrier slides out over it. Opening the levers brings
    the flats up and the plunger carrier sinks 0.8 mm off the drive plate.
    After the dispense cycle, the timeline now plays a cartridge swap (frames
    270-498, DRAWER_KEYS): levers open, drawer 210 mm out the front and back,
    levers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
    [dshaft_lever.stl, top_plate.dxf]
2026-09-30 Keep the D-shaft levers clear of the rail plate and the plunger rods
    Fully open, each lever arm pointed straight out and ended 1.95 mm from the
    plunger rail plate. As the drawer slid out, the full-ring hub also sat in the
    path of the outer plunger rods (x 48-51 mm). The drawer sweep missed that
    because it counted both levers and cartridge as moving and never paired them.
    Everything at the shaft's front end now stays outside KEEP_X (52.5 mm, 1.5 mm
    from the rods), including the trough's inner face (was 51.2, 0.2 mm from the
    rods). The hub wraps the shaft about 190 deg, trimmed flush with the flat and
    at KEEP_X, and an M3 cone-point set screw into a dimple opposite the flat
    holds it instead o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
    [dshaft_lever.stl, dshaft_trough_R.stl]
2026-09-30 Model T-slot extrusion and bolted corner brackets, screw down the pad retainer, add an order summary
    Frame: every 2020 bar now has the B-type T-slot profile (tslot_bar() in
    build_pipette.py, also used for the head side bars and the plunger
    stiffener). Each corner bracket gets 4 button-head M5 bolts into T-nuts
    (frame_bolts, frame_tnuts). The repo bracket's holes are 9 mm in from its
    edges, so the brackets sit 1 mm in from the corner to put the bolts on the
    10 mm slot centerlines. Through a 3 mm plate an M5 x 10 would bottom out on
    the extrusion's core (6.1 mm), so the BOM now calls for M5 x 8 at the corner
    brackets, top plate and base plate.
    The control box moves 3 mm forward to clear the b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
    [control_box_housing_sloped.stl, pad_retainer.stl, plunger_carrier.dxf]
2026-09-30 Animate a full run with real tip pick-up and ejection, raise the head 30 mm
    Demo cycle: the timeline now plays a whole run (CYCLE, 680 frames).
    - Tips go on: a tip rack goes into the nest and the bed rises to press the
    nozzles into the tips.
    - Aspirate: 100 uL per channel from a 1-well reservoir.
    - Dispense: into the 96-well plate, which now has wells.
    - Tips come off: the tilted ejector plate strips them a row at a time
    (tips are 8 row objects) into a waste tray.
    - The D-shaft levers open and the cartridge slides out.
    Liquid shows in the tips, the reservoir and the wells. The old demo cycle and
    the separate drawer-swap keys are gone; collision_report() now sets up tips
    on the nozzles an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
    [Config.h]
2026-09-30 Model every fastener and fix the clashes that turned up
    fasteners() places each screw, bolt, nut, washer and T-nut in the BOM on the
    hole list its part is cut from: 290 fasteners, plus the existing corner-bracket
    bolts and lever set screws. They go in one fast_<joint> object per joint,
    parented to whatever moves them. It also adds the 12 inside corner brackets
    and drills the mounting holes into the bought parts modeled as solids (KFL08s,
    T8 nut flanges, the home switch, the USB socket). Lengths are checked as they
    are placed: T-nut bolts must end 4.2-6.0 mm into the slot, nut bolts must pass
    through their nut, and screws into a part must get enough thread.
    Clashes fixed:
    - Lift T8 nut flang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
    [dshaft_trough_R.stl, lift_base_plate.dxf, lift_home_switch_holder.stl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]
2026-09-30 Write a README for the motorized-lift redesign
    Replaces the original project's two-line description with one for this fork. It covers the status (designed and simulated, not yet built, and what still needs measuring), what changed from the original, how a run works, specs, the repository layout, how to regenerate the files, and credits and licenses. Adds current renders for it in 04_Blender/renders.
2026-10-01 Consolidate fabrication files and streamline the model
    The repo still carried the original lever design: its DXFs (the combined sheet
    among them), STLs, SolidWorks model, firmware and wiring diagram, and the
    rejected lever-lift variant. None of that is part of this build.
    Fabrication files now live in one place:
    - 01_Hardware/ToLaserCut-DXF: 12 files. The two original drawings this build
    still cuts are renamed lift_rail_plate.dxf and corner_bracket.dxf, and the
    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
    [0_combined.DXF, 0_combined.SLDDRW, 1ml syringe barrel.SLDPRT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]
2026-10-02 Replace the heat-shrink nozzles with resin tip cones
    Each syringe's Luer-slip nozzle gets a resin-printed sleeve with a female
    Luer bore inside and the cone the tips seal on outside, so every channel
    has the same fit instead of 96 hand-shrunk ones.
    The cone is 5.3 mm long so the ejector pushes every tip fully clear: at
    full eject the back row ends 1.0 mm below the cone ends and the front row
    4.2 mm. eject_clearance() in the model reports this per row.
    The seal diameters are estimates, so tip_cone_sizing_set.stl holds five
    sizes in 0.1 mm steps to order first and test with your tips. The Luer
    nozzle in the model now follows ISO 80369-7.
    Collision, run-cycle and drawer checks are clean. The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
    [tip_cone.stl, tip_cone_sizing_set.stl]
2026-10-02 Keep every laser-cut hole clear of the plate edges
    SendCutSend asks for a manual review when a hole is closer than 0.91 mm
    to an edge. Four DXFs had holes that close:
    - Lift and plunger rail plates: carriage-screw holes 0.8 mm from the
    edge, inherited from the original design's drawing. Both plates grow
    2 mm at the carriage end and the lift plate's notch moves 2 mm, for
    2.8 mm. make_dxf.py now draws the lift rail plate itself.
    - Cartridge plate: detent holes 0.5 mm from the edge. They move 1 mm
    inward (1.5 mm), and the ledges' M6 holes follow.
    - Tip ejector plate: rod holes 1.0 mm from the edge. The plate grows to
    112 x 102 mm for 3.0 mm.
    Collision, fastener, run-cycle, drawer an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
    [cart_ledge.dxf, cartridge_plate.dxf, lift_rail_plate.dxf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]
2026-10-02 Widen tight clearances and clamp the cartridge plate
    A tolerance review found four fits that normal laser, print and
    molding variation could break:
    - Barrel holes in the cartridge plate go from 6.5 to 6.7 mm, so 6.4 mm
    barrels still pass with undersized holes or fat barrels.
    - The drawer channel opens from 3.3 to 3.5 mm so the plate can't bind.
    Four M4 thumbscrews, two up through each ledge, now press the plate
    against the pipette plate's arms. Otherwise syringe friction could
    shift it in the channel, and that travel would be lost volume. Their
    heads must be 10 mm or less to clear the barrels and grip as the
    drawer slides.
    - The locking frame's slots press 0.2 mm on each flange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
    [cart_ledge.dxf, cart_spacer_R.stl, cartridge_plate.dxf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]
2026-10-03 Back the locking frame with steel and fix pre-order findings
    Pre-order checks (plate stiffness model, printability scan, firmware
    simulation) turned up four problems:
    - The printed locking frame took the tip-loading force and the
    stoppers' drag on its own, bending about 2 mm per 100 N. A 3 mm steel
    lock plate (syringe_lock_plate.dxf) now sits on the frame, which
    thins to 2 mm and only keys the flanges: about 0.03 mm per 100 N.
    Frame screws go to M3 x 16, each on a tab for edge distance.
    - The drawer spacer's stop tab was modeled 0.3 mm off its body and
    would print loose. It now joins the body. The STL export also fails
    any part that isn't a single piece, which merged the tip con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
    [cart_spacer_R.stl, cartridge_handle.stl, syringe_grip_slipfit.stl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]
